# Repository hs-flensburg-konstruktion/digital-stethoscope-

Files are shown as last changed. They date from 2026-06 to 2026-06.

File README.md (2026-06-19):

# Open Source Digital Stethoscope

An affordable and reproducible digital stethoscope designed for local manufacturing using FDM 3D printing. The project aims to provide a robust and repairable platform for recording heart and lung sounds, especially in regions with limited access to medical equipment.

---

## Motivation

Commercial digital stethoscopes are often expensive and difficult to obtain in many parts of the world. The goal of this project is to develop an open-source hardware platform that can be manufactured locally with commonly available components and a standard FDM 3D printer.

The design was developed in collaboration with a physician from Sudan, who helped define the main requirements and intended use cases.

---

## Design Requirements

* Operation in ambient temperatures up to 60 °C
* Resistance to cleaning with soap water and disinfectants
* Mechanical robustness against drops and impacts
* Simple assembly with minimal tools
* Replaceable electronics
* Local manufacturability using FDM 3D printing
* Open-source documentation for easy reproduction

---

## Hardware

### Main Components

* ESP32-S3 development board
* MEMS microphone (SPH0641LU4H)
* 3.7 V LiPo battery (900 mAh)
* Battery charging module (BMS)
* Acoustic membrane made from PE film
* Three-part 3D printed enclosure

---

## Mechanical Design

The enclosure consists of three parts:

1. Electronics carrier
2. Rear housing with external thread
3. Front housing with internal thread

The modular design allows all electronic components to be installed after printing and replaced if necessary.

The enclosure is optimized for FDM manufacturing and can be printed in PLA for prototyping or PETG/ABS for final applications.

---

## Repository Structure

```
3D-Models/
├── f3d
├── par
└── stp

Docs/
├── Assembly
└── pictures
└─ Bill_of_Materials
└─ Stetoscope_Requirements

Electronics/

Firmware/

```

---

## Bill of Materials

A complete Bill of Materials (BOM) is available in the BOM folder.

Main components include:

| Component | Quantity |
| --- | --- |
| ESP32-S3 | 1 |
| MEMS microphone SPH0641LU4H | 1 |
| LiPo battery 900 mAh | 1 |
| Battery charging module | 1 |
| Acoustic membrane (PE film) | 1 |
| 3D printed housing parts | 3 |

---

## Assembly

Detailed assembly instructions with pictures are provided in the Assembly folder.

The assembly process consists of:

1. Installing the acoustic membrane
2. Inserting the battery
3. Installing the battery charging module
4. Mounting the ESP32-S3
5. Installing the MEMS microphone
6. Inserting the electronics carrier into the housing
7. Closing the enclosure
8. Attaching the membrane cap

---

## Manufacturing

### Recommended Materials

* PLA (prototyping)
* PETG (recommended)
* ABS (high-temperature environments)

### Manufacturing Method

FDM 3D Printing

---

## Current Status

Prototype stage

* Mechanical design completed
* First integrated prototype assembled
* Electronics integration demonstrated
* Signal processing and software development are still under development

---

## Lessons Learned

During development several challenges were identified:

* Inconsistent CAD workflows between different CAD systems led to interface issues.
* Missing version control resulted in printing outdated part revisions.
* Some system requirements were identified only during later design iterations.

These findings highlighted the importance of unified CAD workflows, proper version management and early system-level planning.

---

## Future Work

* Signal processing and filtering
* Smartphone connectivity
* Acoustic characterization and validation
* Clinical evaluation
* Improved power management
* Integration of an on/off switch
* Field testing and further open-source development

---

## Contributors

Developed as part of the "Konstruktion 3 – Kunststoffkonstruktion" course at flensburg university of applied science.

Mechanical design and hardware integration by the student team in collaboration with the supervising professor.

---

## License

This project is intended to be released as Open Source Hardware.

CAD files, documentation and source code are provided to enable reproduction, modification and further development by the community.

# Print Settings – Electronics Plate

This document contains the print settings used to manufacture the electronics plate using FDM 3D printing.

## Hardware

| Parameter | Value |
|---|---|
| Part | Electronics Plate |
| Printer | Bambu Lab A1 |
| Nozzle Diameter | 0.4 mm |
| Filament | PLA |

## Print Settings

| Parameter | Value |
|---|---|
| Layer Height | 0.08 mm (Extra Fine) |

## Support Settings

| Parameter | Value |
|---|---|
| Supports Enabled | Yes |
| Support Type | Tree (Auto) |
| Support Style | Standard |
| Threshold Angle | 15° |
| Build Plate Only | Yes |
| Critical Regions Only | Yes |
| Remove Small Overhangs | No |

## Description

The electronics plate was printed using a Bambu Lab A1 equipped with a 0.4 mm nozzle and PLA filament. A layer height of 0.08 mm was selected to achieve a high level of detail and surface quality.

Tree supports were enabled and automatically generated by the slicer. Supports were restricted to the build plate and only applied to critical overhangs, reducing both material consumption and post-processing effort.

## Software

- Bambu Studio

## Notes

- Optimized for high-quality surface finish
- Minimal support material usage
- Easy support removal through tree support structures
- Suitable for functional and aesthetic prototype parts

## License

The print settings provided in this repository may be freely used, modified, and distributed.

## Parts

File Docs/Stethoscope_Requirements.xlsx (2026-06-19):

Nr. | Kategorie | Unterkategorie | Anforderung | Kategorie | Intressenhalter | Wichtigkeit | Erfüllt | Nicht erfüllt | Bemerkungen
1 | Mechanisch | Verarbeitung | Das gesamte Stethoskop muss ohne scharfe Kanten konstruiert werden, da dies ein Verletzungsrisiko darstellen kann. | Technische Anforderung | Hersteller | Basis | x
2 |  | Werkzeuglose Zerlegbarkeit | Kompakt für Transport; einfacher Zugriff auf das Elektronik-Modul. | Millieu Anforderung | Hersteller | Basis | x
3 |  | Membran | Die Membran muss möglichst Wiederstandsfest sein, um nicht zu leicht kaputt zu gehen. Gleichzeitig muss sie den Klang optimal übertragen, weshalb eine gewisse Spannung erforderlich sein wird. | Technische Anforderung | Kunde | Basis | x
4 |  | Generelle Robustheit des Stethoskops | Das Stethoskop muss eine alltäglichen Benutzung durch einen Arzt oder durch geschultes Personal auf Dauer aushalten. Hierbei wird vorallem die Verschmutzung durch Staub oder Sand eine übergeornete Rolle spielen (geographisch Bedingt). | Millieu Anforderung | Kunde | Basis | x
5 |  | "Modulare"-Bauweise | Standardisierter Bauraum im Inneren für verschiedene Elektronik-Kassetten. | Technische Anforderung | Kunde | Basis | x
6 |  | Verfügbarkeit von Teilen | Die verwenden Teile müssen in Massen vorhanden sein, sodass der Zusammenbau des Stethoskops nicht von Lieferschwierigkeiten beeinflusst wird. | Technische Anforderung | Hersteller | Begeisterung | x
7 | Handhabung | Auflage auf Körper | Das Koppfstück muss gut an den Körper gepresst werden können, um den Luftspalt zwischen Membran und Körper so klein wie möglich zu halten. | Technische Anforderung | Kunde | Basis | (x)
8 |  | Reinigung | Der Kopf des Stethoskops, sowie die Ohreinsätze müssen einem häufig frequentiertes Säubern aushalten. Dafür verwendet werden Ethanol, Seife und Wasser. | Technische Anforderung | Kunde | Basis | (x)
9 |  | Intuitive Bedienbarkeit | Das Stethoskop sollte eine Form besitzen die den Einsatz ohne große Erklärungen ermöglicht. | Technische Anforderung | Kunde | Leistung | (x)
10 |  | Bedienbarkeit | Die Bedienung des Stethoskops sollte mit einer Hand möglich sein. | Technische Anforderung | Kunde | Leistung | x
11 |  | Handhabung | Um eine gute Handhabung zu gewährleisten sollte eine minimales Gewicht erreicht werden, damit ein präzises führen mit einer Hand möglich ist. Unser Schätzwert liegt hierbei zwischen 250 - 400 Gramm. | Technische Anforderung | Kunde | Begeisterung | x
12 | Audio & Sensorik | Übertragung von Aufnahmegeräuschen | Die Geräusche, die von dem Mikrophon aufgenommen werden, müssen weiter an ein Handy oder an ein geeignetes Aufnahmegerät geleitet werden können. | Technische Anforderung | Kunde | Basis |  | x
13 |  | Aufnahme von Körpergeräuschen | Im generellen muss das Stethoskop in der Lage sein die unterschiedlichsten Geräusche so aufzunehmen, dass diese für Forschungs- und/oder Behandlungszwecke genutzt werden können. | Technische Anforderung | Kunde | Basis |  | x
14 |  | Schallübertragung | Das Mikrophon im Stethoskop muss eine gute Tonqualität im Bereich 20 - 2000 Hz besitzen. | Technische Anforderung | Kunde | Basis |  | x
15 |  | Tonverstärkung | Generell muss es möglich sein, das Geräusch zu Verstärken. Ein guter Multiplikator würde zwischen 18 - 50 liegen. | Technische Anforderung | Kunde | Basis |  | x
16 |  | Einstellbarer Bereich | Bei Mikrophonen die eine Bereich bis 20 kHz ermöglichen sollte einstellbar sein, in welchem Frquenzbereich die Aufnahme hochauflösend sein muss. | Technische Anforderung | Kunde | Basis |  | x
17 |  | ANR (activ noise reduction) | Das Mikrophon soll Hintergrndgeräusche heruafiltern können. Diese Funktion muss jedoch an und ausschaltbar sein. | Millieu Anforderung | Kunde | Leistung |  | x
18 | Material & Konstruktion | Open Source Konstruktion | Das gesamte Projekt muss online einsehbar und begreifbar sein. Dafür muss mindestens das Endprodukt in seinen Einzelteilen und die Funktionserklärung online frei zur Verfügung stehen. | Technische Anforderung | Hersteller | Basis | x
19 |  | 3D-Druckbarkeit | Bis auf technich anspruchsvolle Teile oder Teile die einen gewissen schwer zu reproduzierenden Charakter haben, sollten alle Teile in einem 3D-Drucker gefertigt werden können | Technische Anforderung | Hersteller | Basis | x
20 |  | Kostengünstig Bestandteile | Bestandteile sollten insgesamt einen Wert von 18€ nicht übersteigen. | Wirtschaftliche Anforderung | Hersteller | Basis |  | x | Der Preis dürfte sich auf 20-30€ belaufen
21 |  | Materialverträglichkeit | Die verwendeten Materialien müssen alle unbedenklich für die Nutzung auf der nackten Haut sein. | Technische Anforderung | Kunde | Basis | (x)
22 |  | Temperaturbeständigkeit | Da das Stethoskop unter teilweise extremen Bedingungen verwendet werden muss, sollte es problemlos bei einer Temperatur von 60° Celsius benutzt werden können. | Technische Anforderung | Kunde | Leistung | x
23 | Energieversorgung | Verarbeitung elektronischer Bauteile | Bauteile in denen Strom fließt oder an denen eine Spannung anliegt sollten so verbaut sein, dass es unter keinen Umständen zu einem Hautkontakt kommen kann. | Technische Anforderung | Hersteller | Basis | x
24 |  | Energieversorgung | Die Enregieversorgung für das Mikrophon muss durch Batterien oder durch die Verbindung zu einem Handy (oder ähnlichem) gewährleitet sein | Technische Anforderung | Kunde | Basis | x

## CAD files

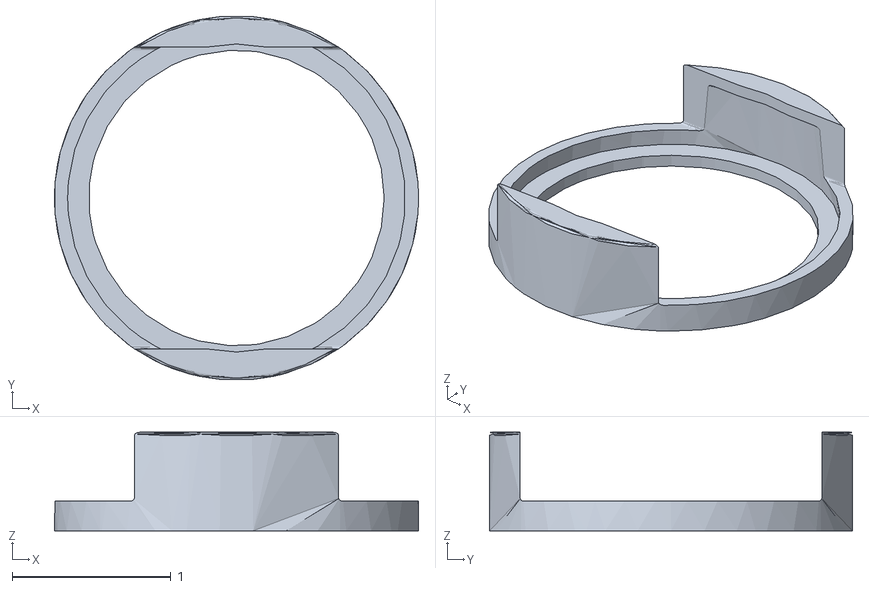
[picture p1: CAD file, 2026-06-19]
3D-Models/stl/Crown_version_c.stl
2.29 x 2.28 x 0.62

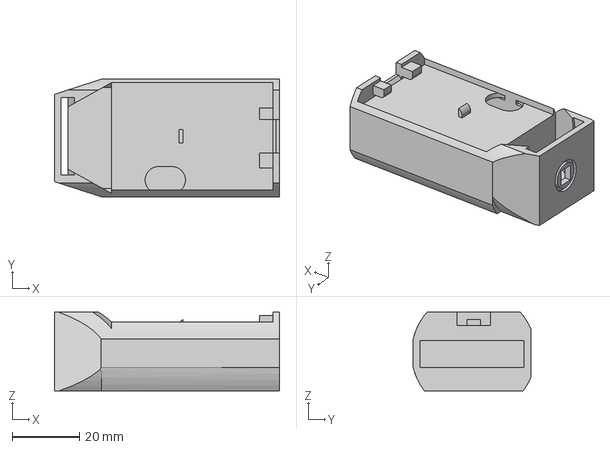
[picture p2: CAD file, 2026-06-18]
3D-Models/stp/electronic_board.step
67.0 x 35.0 x 23.5 mm

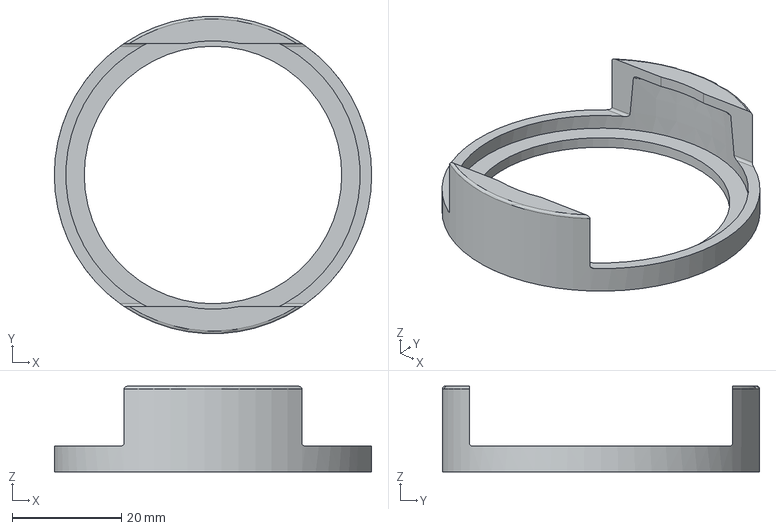
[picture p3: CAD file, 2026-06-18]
3D-Models/stp/Crown_version_3.stp
58.2 x 58.1 x 15.7 mm

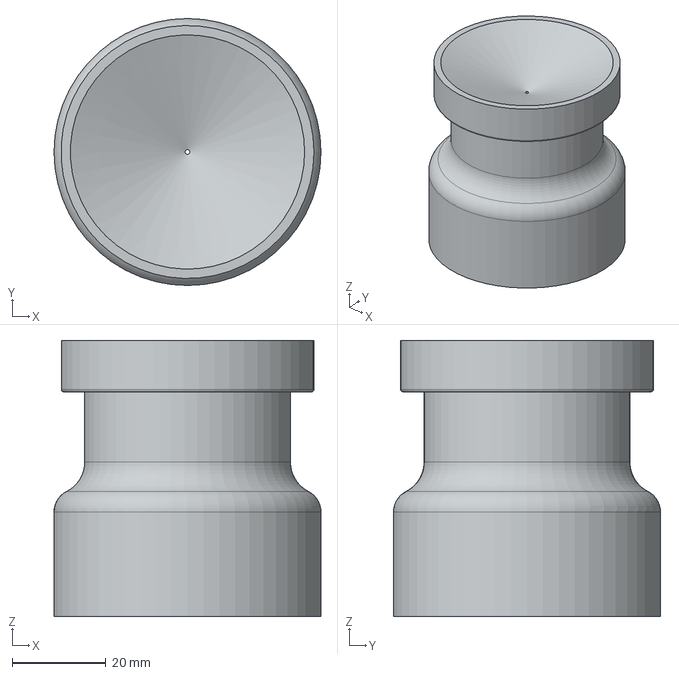
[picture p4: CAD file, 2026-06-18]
3D-Models/stp/Front_part.stp
57.0 x 57.0 x 59.0 mm

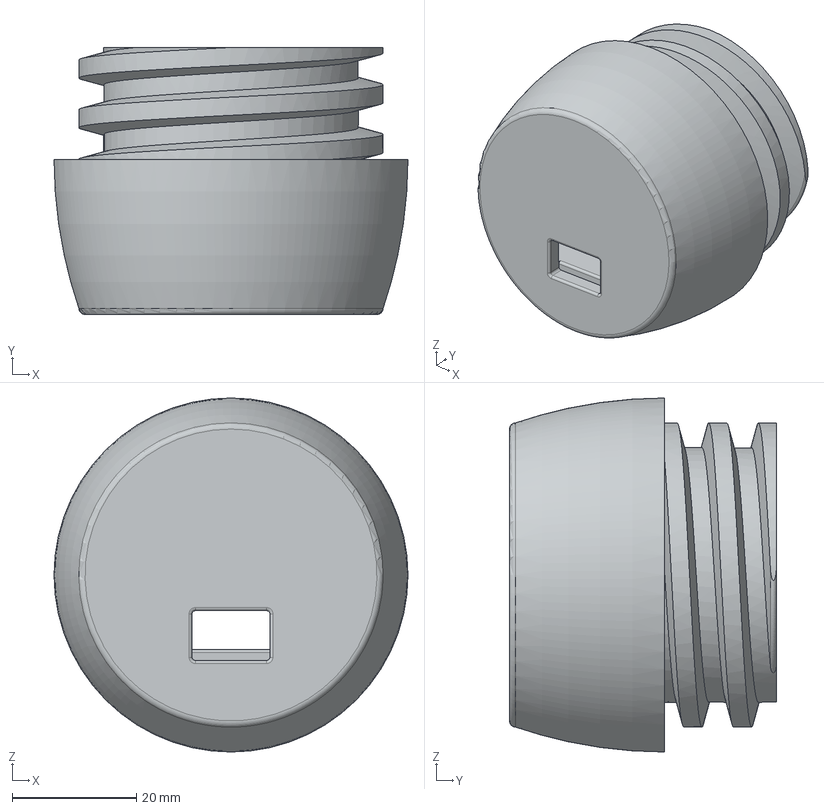
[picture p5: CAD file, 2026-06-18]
3D-Models/stp/Back_part.stp
57.0 x 43.0 x 57.0 mm

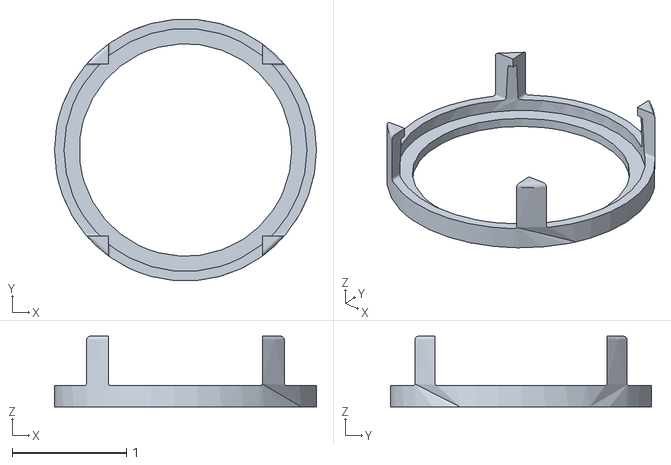
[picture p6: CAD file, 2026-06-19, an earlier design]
3D-Models/stl/Crown_version_b.stl
2.29 x 2.28 x 0.62

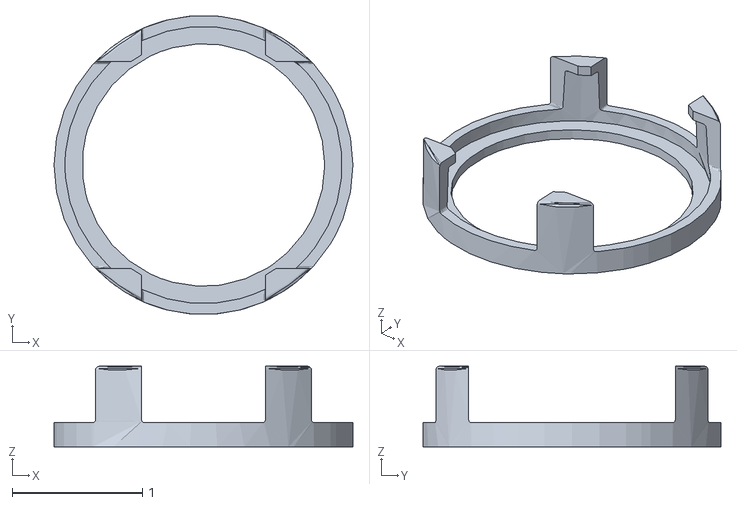
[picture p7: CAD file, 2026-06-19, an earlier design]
3D-Models/stl/Crown_version_a.stl
2.29 x 2.28 x 0.62

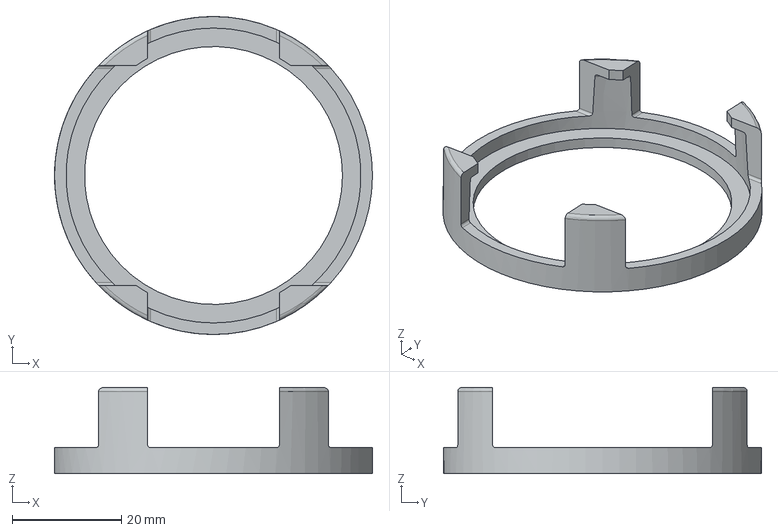
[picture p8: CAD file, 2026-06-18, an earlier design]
3D-Models/stp/Crown_version_1.stp
58.2 x 58.2 x 15.7 mm

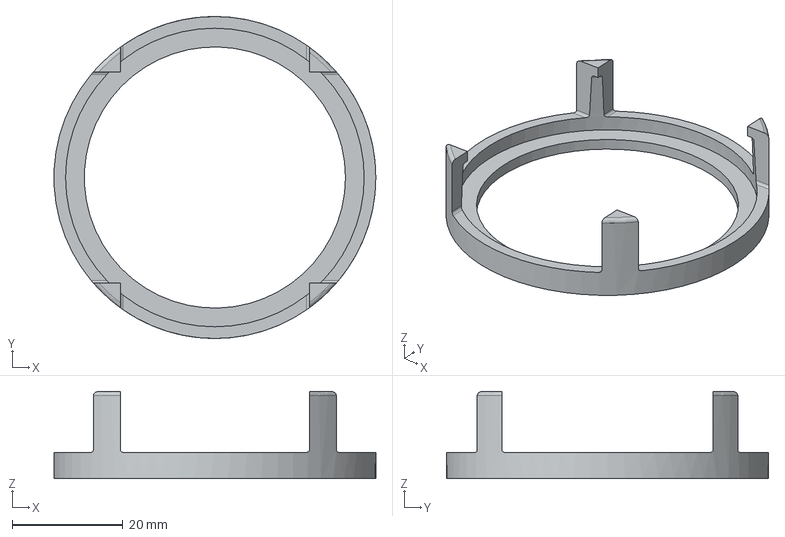
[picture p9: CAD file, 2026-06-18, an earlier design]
3D-Models/stp/Crown_version_2.stp
58.2 x 58.2 x 15.7 mm

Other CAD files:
3D-Models/f3d/electronic_board.f3d
3D-Models/stl/Back_part.stl
3D-Models/stl/Front_part.stl
3D-Models/stl/electronic_board.stl

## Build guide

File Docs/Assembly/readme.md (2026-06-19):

Assembly Instructions

All components required for the assembly are shown in picture_1.

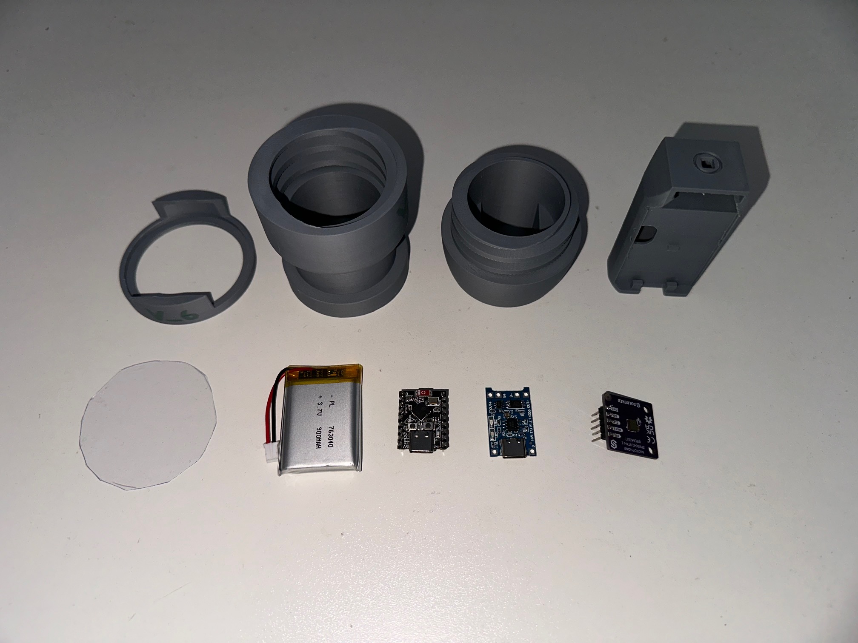
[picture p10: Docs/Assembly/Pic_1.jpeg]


Step 1: Install the Acoustic Membrane

Insert the PE membrane into the membrane cap as shown in picture_2.

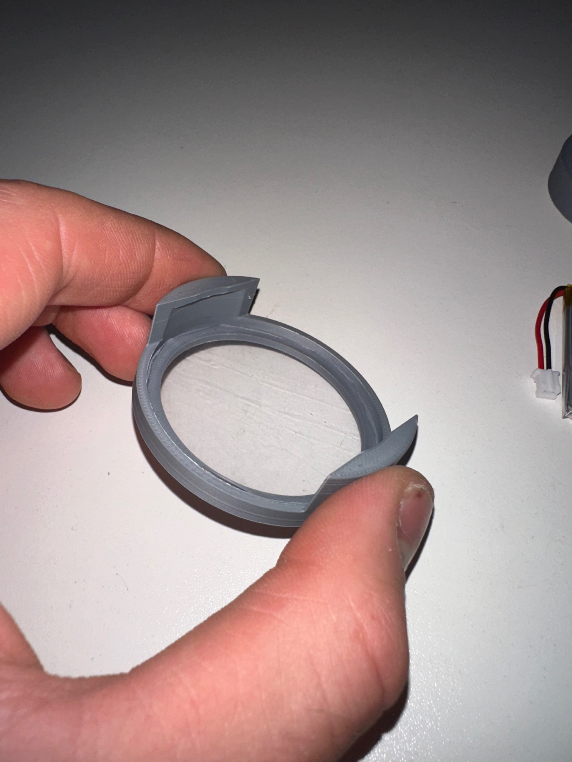
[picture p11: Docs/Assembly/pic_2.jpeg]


Step 2: Insert the Battery

Slide the LiPo battery into the battery compartment from the rear side of the electronics carrier. Make sure that the battery wires are routed upwards as shown in picture_3 and picture_4.

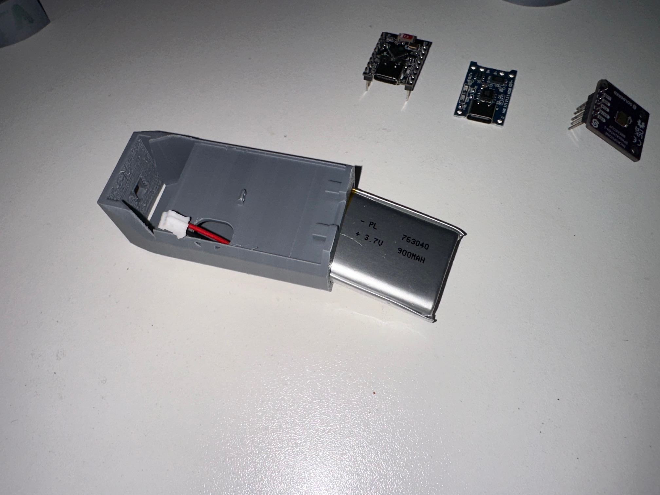
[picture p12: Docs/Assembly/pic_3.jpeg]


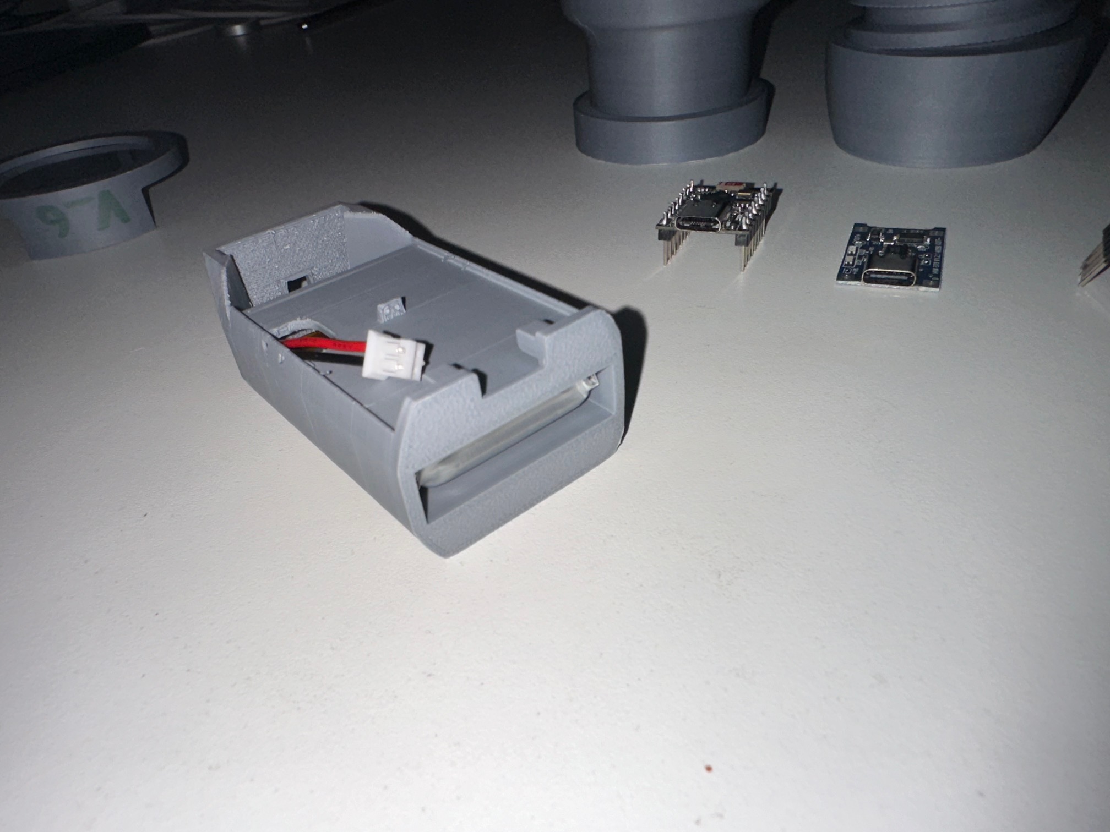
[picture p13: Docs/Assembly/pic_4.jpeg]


Step 3: Mount the Battery Management System

Snap the battery charging module (BMS) into its designated position above the battery compartment. The correctly installed module is shown in picture_5 and picture_6.

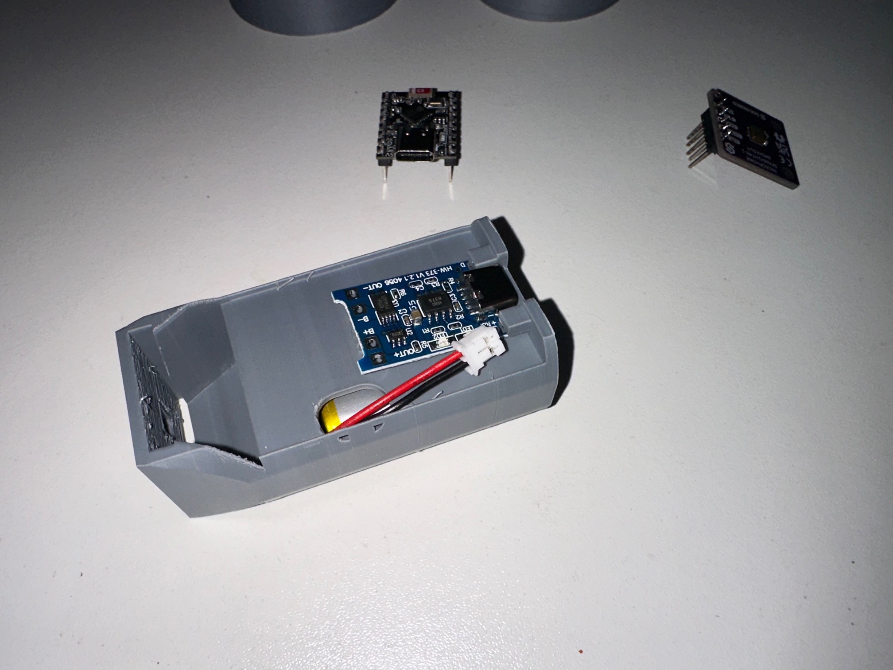
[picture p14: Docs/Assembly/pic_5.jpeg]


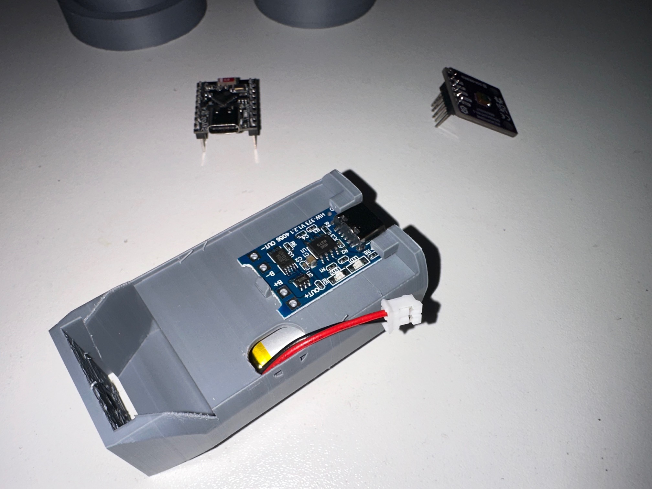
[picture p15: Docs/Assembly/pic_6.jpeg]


Step 4: Install the ESP32-S3

Insert the ESP32-S3 from the front side of the electronics carrier. Carefully press the pin header into the corresponding slot until the board is securely seated (picture_7, picture_8).

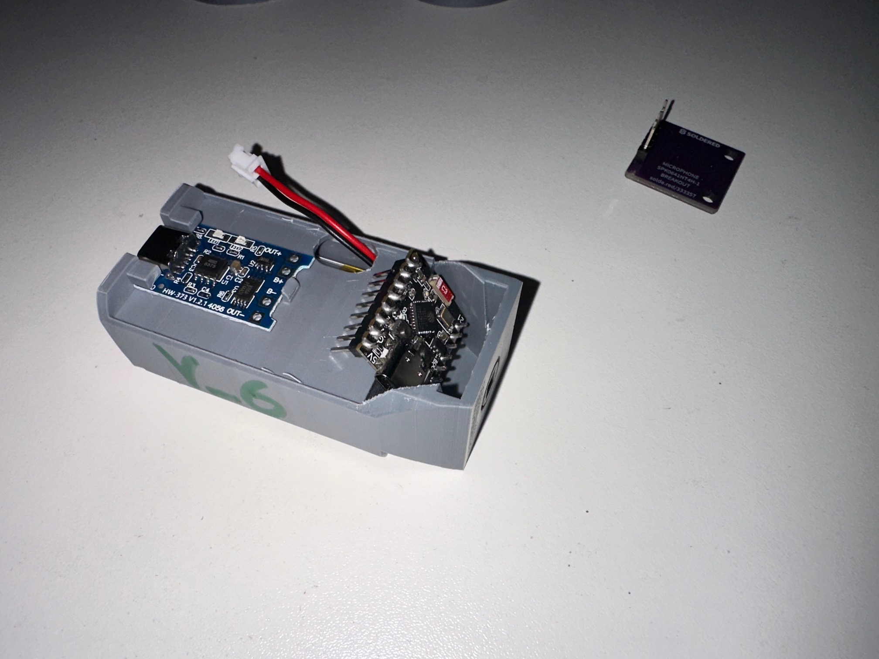
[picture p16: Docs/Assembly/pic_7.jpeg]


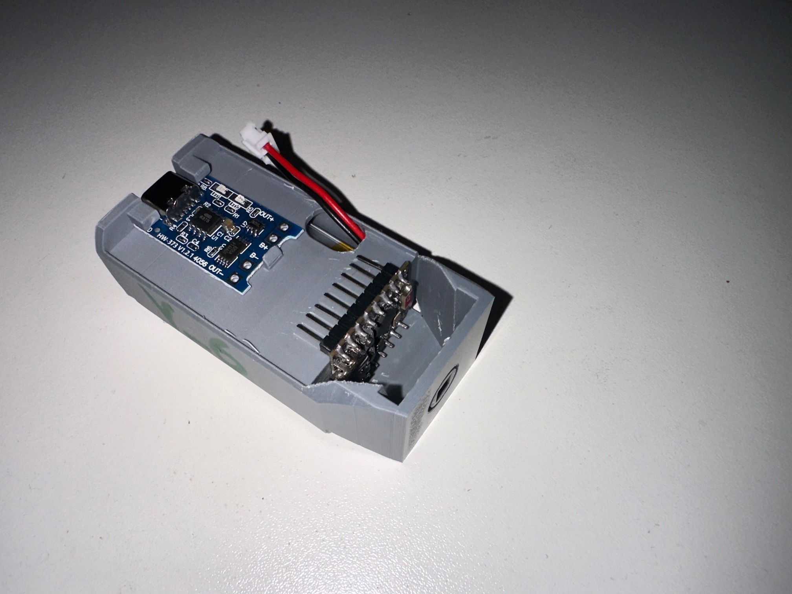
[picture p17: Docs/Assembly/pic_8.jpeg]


Step 5: Install the MEMS Microphone

Insert the MEMS microphone module from the top into the guiding rails and gently press it into its final position (picture_9, picture_10).

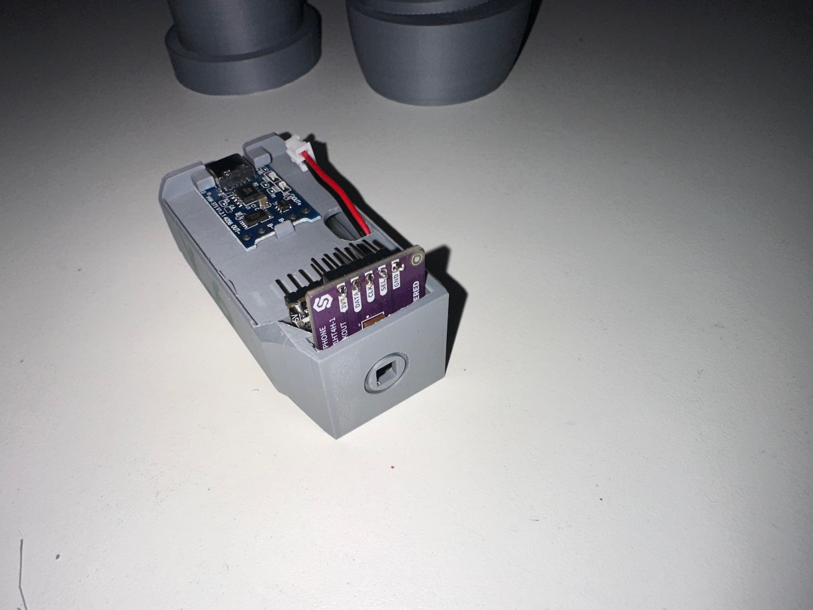
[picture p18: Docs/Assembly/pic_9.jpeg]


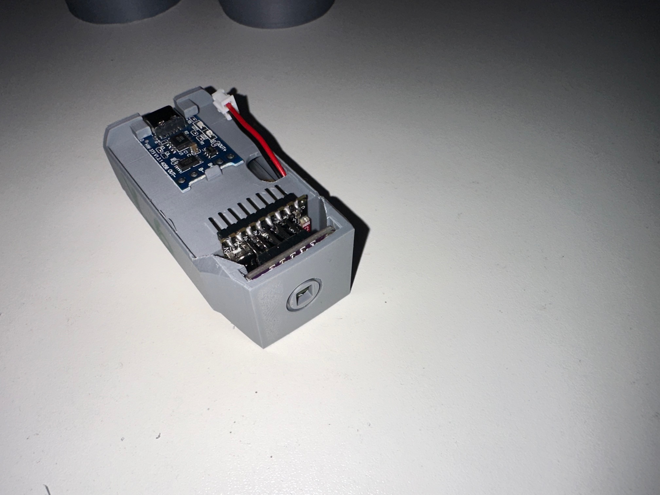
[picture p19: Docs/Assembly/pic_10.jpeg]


Step 6: Check Microphone Alignment

After installation, only the microphone itself should protrude through the opening in the electronics carrier, as shown in picture_11.

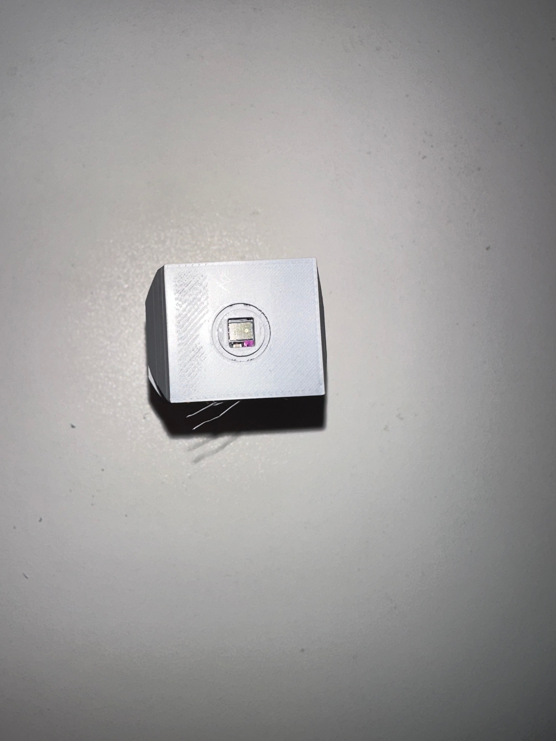
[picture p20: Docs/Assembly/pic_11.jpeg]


Step 7: Insert the Electronics Carrier

Place the fully assembled electronics carrier into the rear housing part as shown in picture_12 and picture_13.

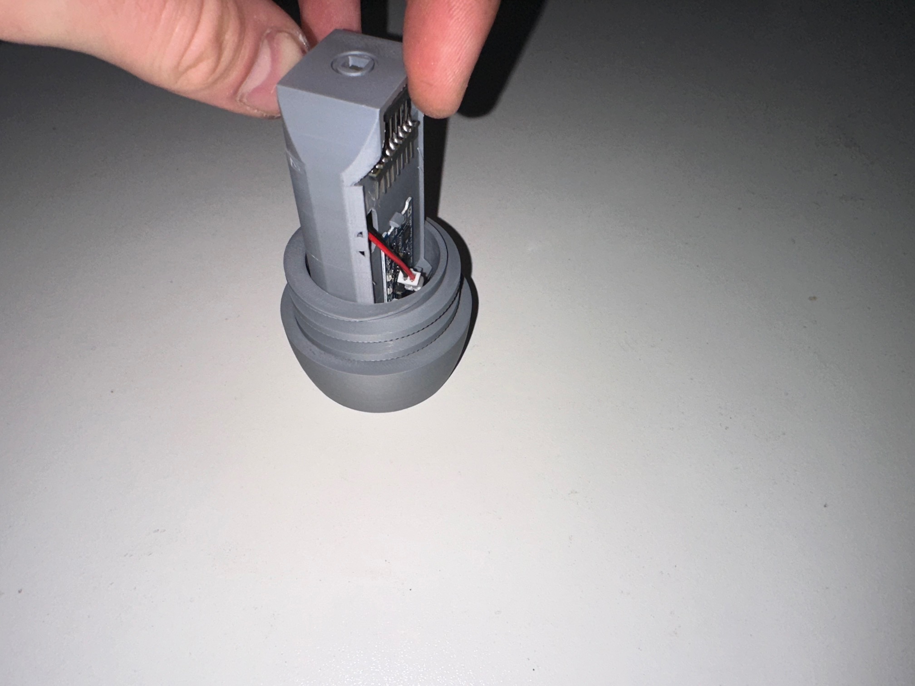
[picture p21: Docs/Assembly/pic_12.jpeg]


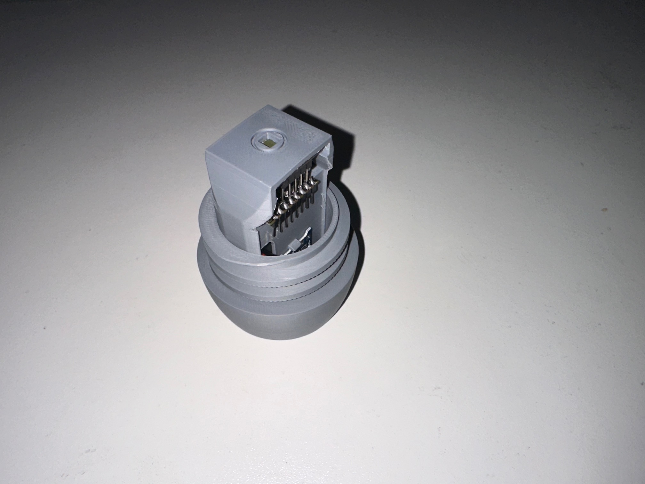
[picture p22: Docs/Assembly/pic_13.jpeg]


Step 8: Close the Housing

Screw the front housing part onto the rear housing until the enclosure is fully closed (picture_14, picture_15).

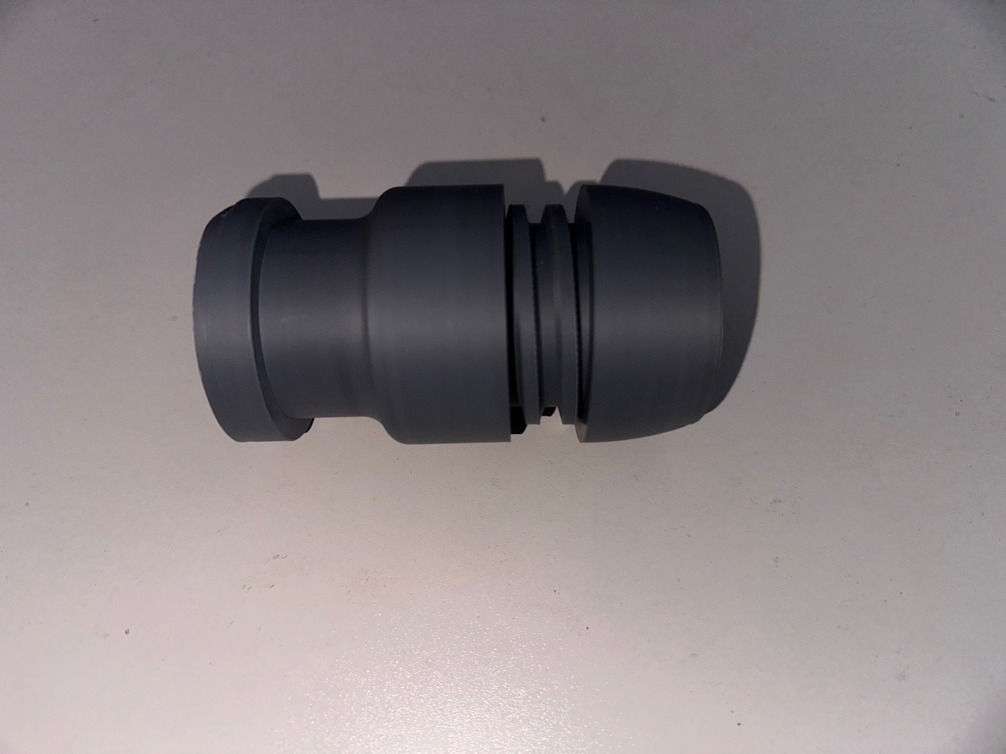
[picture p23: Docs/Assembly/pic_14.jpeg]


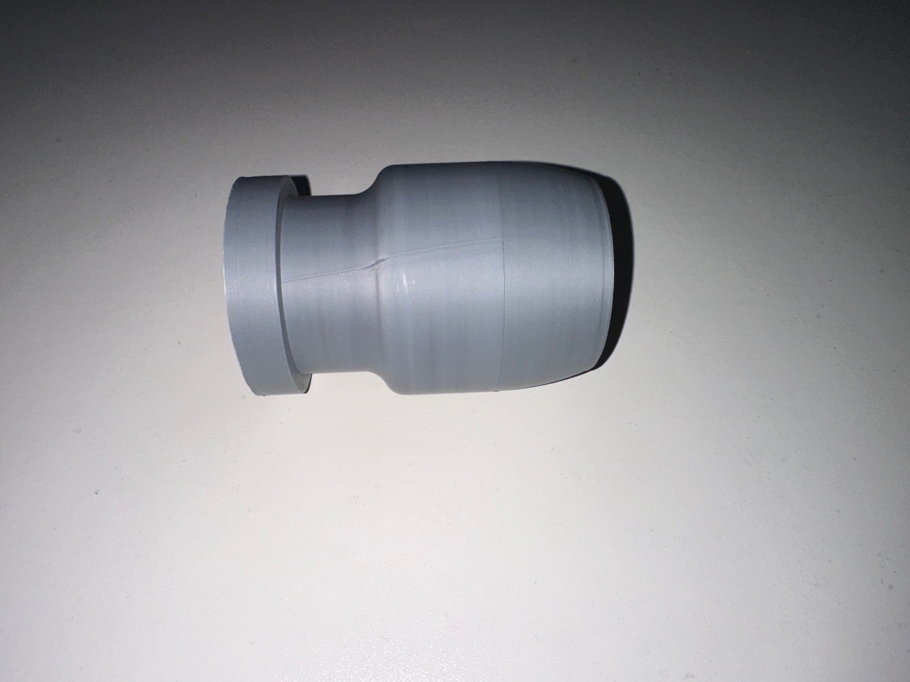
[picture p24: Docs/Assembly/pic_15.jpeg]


Step 9: Attach the Membrane Cap

Install the membrane cap on the front side of the housing (picture_16).

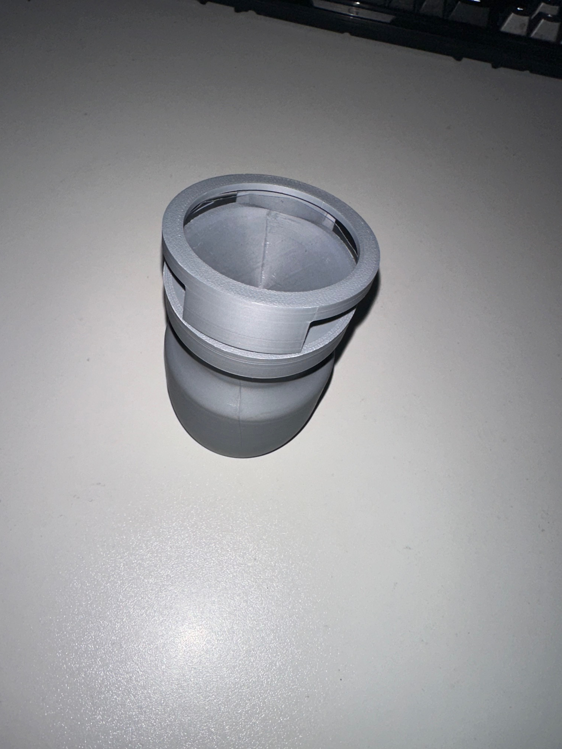
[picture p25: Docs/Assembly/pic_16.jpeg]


Step 10: Finished Assembly

The digital stethoscope is now fully assembled (picture_17).

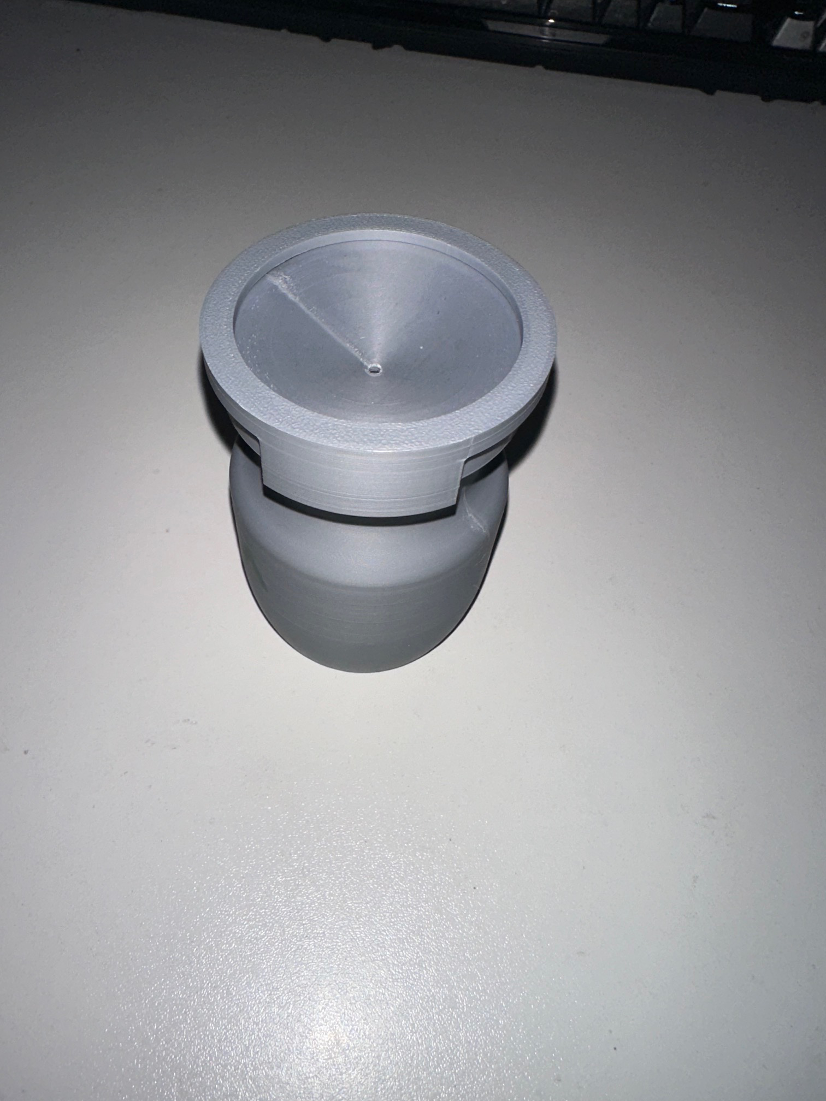
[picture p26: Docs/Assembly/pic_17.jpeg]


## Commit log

2026-04-23 Erste version der Stethoskop-Hülle
    [Stethoskop V4 Oben.scad, Stethoskop V4 Unten.stl]
2026-06-19 Delete 3D-Models/stl/README.md
    Not needed.
2026-06-19 Fix typo in assembly instructions
